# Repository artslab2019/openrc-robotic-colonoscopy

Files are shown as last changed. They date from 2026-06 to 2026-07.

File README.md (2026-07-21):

# OpenRC: An Open-Source Robotic Colonoscopy Framework for Multimodal Data Acquisition and Autonomy Research

**MICCAI 2026** &nbsp;·&nbsp; Siddhartha Kapuria, Mohammad Rafiee Javazm, Naruhiko Ikoma, Joga Ivatury, Mohammad Ali Nasseri, Nassir Navab, Farshid Alambeigi





OpenRC is an open-source framework that **robotizes a conventional clinical colonoscope without altering its workflow.** A modular robotic platform actuates the scope's existing insertion-tube and steering knobs while simultaneously recording the endoscopic video, operator commands, low-level actuation signals, and the distal-tip pose. The result is a reproducible testbed for studying robotic colonoscopy, imitation/vision-language-action learning, and surgical autonomy. 

This repository provides a higher-level-of-detail overview of the **hardware platform** and the **colon phantom testbed**. Full analytical design, optimization, and fabrication derivations are documented in our companion paper, [arXiv:2509.10735](https://arxiv.org/abs/2509.10735).

This repository also includes the OpenRC dataset release accompanying this platform. The dataset consists of synchronized multimodal trajectories collected using this platform on real colon phantoms, spanning navigation, scanning, and failure/recovery scenarios.

---

## System Overview

OpenRC system overview

OpenRC is organized into four interconnected subsystems:

1. **Control System** — operator interface and onboard compute.
2. **Robotic System** — the clip-on actuation hardware (feeding + bending modules).
3. **Video Capture** — clinical imaging chain and frame acquisition.
4. **Environment & Sensing** — the colon phantom and electromagnetic tip tracking.

---

## Experimental Setup

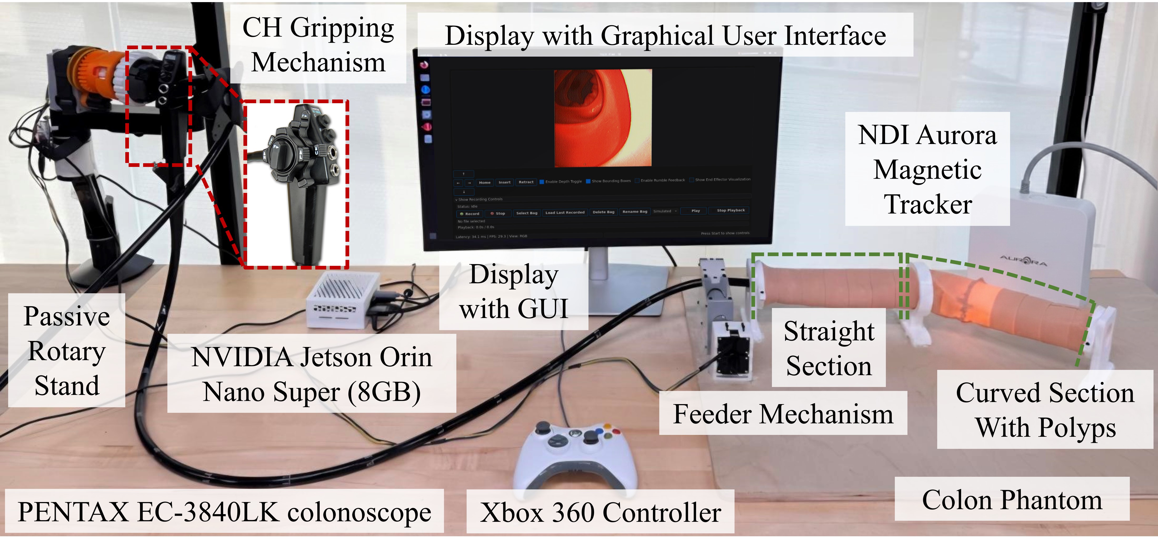
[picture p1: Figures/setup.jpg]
OpenRC experimental setup


The complete benchtop testbed. A **PENTAX EC-3840LK colonoscope** is held on a passive rotary stand, with its distal end gripped by the **CH (collet-chuck) bending mechanism** and its insertion tube driven by the **feeder mechanism**. An **Xbox 360 controller** teleoperates the scope through the **NVIDIA Jetson Orin Nano Super (8 GB)**, which also runs the **GUI** shown on the display. The scope is navigated through a custom **colon phantom** while the **NDI Aurora magnetic tracker** records 6-DoF distal-tip pose.

---

## Hardware Platform

OpenRC is a **retrofit**: it clamps onto an unmodified clinical colonoscope and drives the same insertion tube and steering knobs a clinician would operate by hand. Two decoupled, 3D-printable modules provide the actuation, while teleoperation, compute, and synchronized recording run onboard an NVIDIA Jetson.

| | |
|---|---|
| **Compute** | NVIDIA Jetson Orin Nano Super (8 GB) |
| **Control** | Xbox controller → ROS2 Humble → Dynamixel U2D2 |
| **Feeding module** | 1-DoF insertion/retraction via a motor-driven spline shaft and feeder-roller |
| **Bending module** | Steering via a nested collet-chuck gripping the scope's existing knobs |
| **Imaging** | Clinical video processor + frame grabber, 383 × 396 @ 30 fps |
| **Sensing** | NDI Aurora EM tracker, 6-DoF distal-tip pose |
| **Scope** | PENTAX EC-3840LK (unmodified) |

The two fabricated actuation modules:

Assembled feeding module

*Feeding module — a motor drives the spline shaft through a flexible coupling, advancing the scope's insertion tube.*

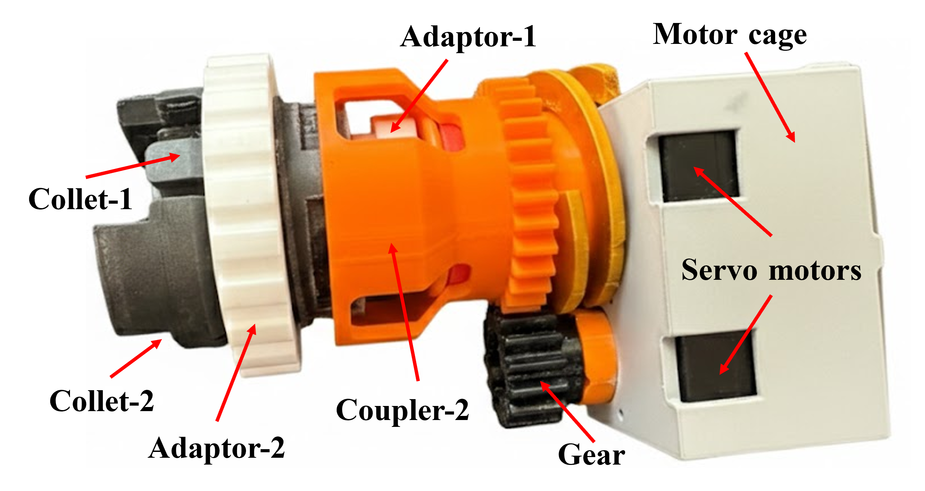
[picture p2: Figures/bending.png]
Assembled bending module


*Bending module — nested collets clamp onto the concentric steering knobs and are driven through a gear train to deflect the distal tip.*

> **Further details are provided in [`docs/`](docs/):** mechanical design and CAD ([Hardware Platform](docs/hardware.md)), the ROS2 control architecture ([Software & ROS2 Stack](docs/software.md)), and the phantom build ([Colon Phantom Fabrication](docs/phantom-fabrication.md)). For the analytical design and optimization, see the companion paper [arXiv:2509.10735](https://arxiv.org/abs/2509.10735).

---

## Documentation

| Document | Contents |
|---|---|
| [Hardware Platform](docs/hardware.md) | Control system, feeding/bending modules (CAD + dimensions), video capture, sensing |
| [Software & ROS2 Stack](docs/software.md) | ROS2 node graph, topics, and control/recording architecture (implementation details) |
| [Colon Phantom Fabrication](docs/phantom-fabrication.md) | Polyp and colon-wall molding/casting procedure |
| [Bill of Materials](docs/bill-of-materials.md) | Components, part numbers, and suppliers |
| [CAD & Assembly Files](docs/assembly.md) | STEP assembly exports and STL files for printable parts |

---

## Dataset

The OpenRC dataset is hosted on HuggingFace in **[LeRobot](https://github.com/huggingface/lerobot) format**, under NVIDIA's PhysicalAI Open-H-Embodiment collection:

> **`nvidia/PhysicalAI-Robotics-Open-H-Embodiment`** → [`Endoscopy/ut_austin/arts_lab/colonoscope_lerobot`](https://huggingface.co/datasets/nvidia/PhysicalAI-Robotics-Open-H-Embodiment/tree/main/Endoscopy/ut_austin/arts_lab/colonoscope_lerobot)

| | |
|---|---|
| **Episodes** | 1,894 teleoperated trajectories |
| **Frames** | 2,095,587 (~19.4 hours) |
| **Camera** | 383 × 396 endoscopic video @ 30 fps |
| **Size** | 19.7 GB |
| **Recording** | ROS2 Humble; calibration-based time alignment across streams |
| **Collection** | 5 intermediate-skill operators, 10 structured task variations, Nov 2025 – Jan 2026 |
| **License** | CC BY 4.0 |

**Task variations** span routine navigation, induced failure events, and recovery behaviors.

### Example Episode

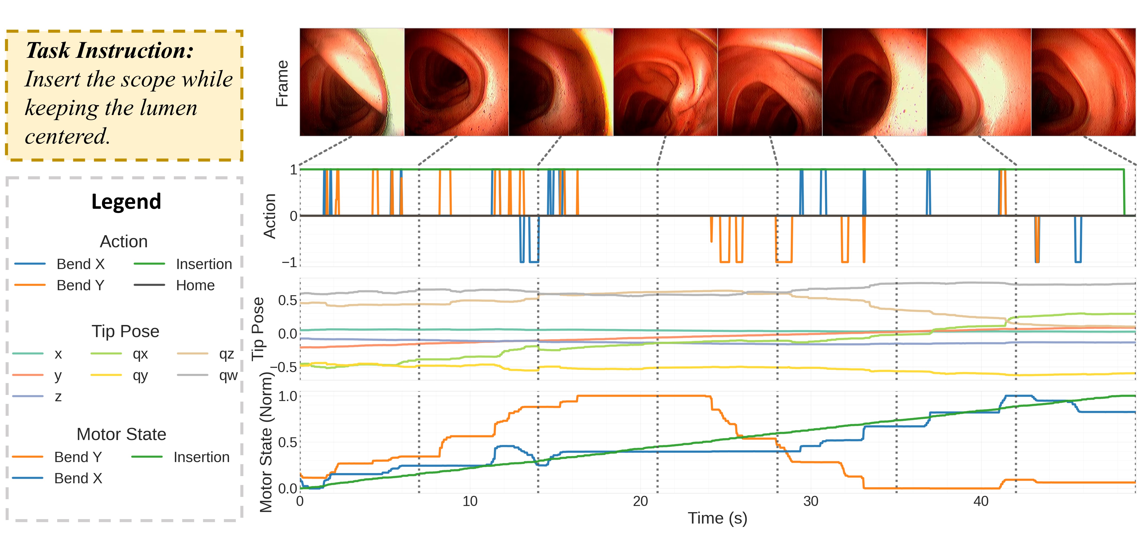
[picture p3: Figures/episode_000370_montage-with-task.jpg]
Example OpenRC episode


A representative episode (`episode_000370`) for the task *"Insert the scope while keeping the lumen centered."* The top row shows sampled endoscopic frames; below, the synchronized operator **action** (bend X/Y, insertion, home), 7-DoF **tip pose** from the EM tracker, and low-level **motor state** are plotted over the episode timeline — illustrating how all streams are time-aligned within each trajectory.

### Modalities & Schema

- **Endoscopic video** — RGB camera feed (384 × 383 @ 30 fps).
- **NDI Aurora EM tracking** — distal-tip pose.
- **Xbox controller** — operator teleoperation inputs.

| Key | dtype / shape | Description |
|-----|---|---|
| `observation.images.endoscope` | video `[396, 383, 3]` | Endoscopic RGB camera feed (AV1 / yuv420p) |
| `observation.state` | int32 `[3]` | Motor positions: `motor_1`, `motor_2`, `motor_3` |
| `observation.ndi_cartesian_absolute` | float32 `[7]` | Absolute tip pose in NDI frame: `x, y, z, qx, qy, qz, qw` |
| `observation.ndi_cartesian_relative` | float32 `[6]` | Relative tip motion: `dx, dy, dz, droll, dpitch, dyaw` |
| `action` | float32 `[4]` | `bend_x`, `bend_y`, `insertion`, `home` (ranges: `[-1, 1]` for bend/insertion, `[0, 1]` for home) |

### Quickstart

The dataset uses **LeRobot format v2.1**, which requires **`lerobot==0.33`**.

1. Install `torch` by following the [official PyTorch installation instructions](https://pytorch.org/get-started/locally/).
2. Install the remaining dataset and visualization dependencies:

```bash
pip install huggingface_hub "lerobot==0.33" numpy tqdm rerun
```

3. Download the dataset subset from HuggingFace:

```python
from huggingface_hub import snapshot_download

local_dir = snapshot_download(
    repo_id="nvidia/PhysicalAI-Robotics-Open-H-Embodiment",
    repo_type="dataset",
    allow_patterns="Endoscopy/ut_austin/arts_lab/colonoscope_lerobot/*",
)
print("Downloaded to:", local_dir)
```

4. Load it with the LeRobot API from the downloaded subfolder:

```python
from lerobot.common.datasets.lerobot_dataset import LeRobotDataset

dataset = LeRobotDataset(
    repo_id="nvidia/PhysicalAI-Robotics-Open-H-Embodiment",
    root=f"{local_dir}/Endoscopy/ut_austin/arts_lab/colonoscope_lerobot",
)

print(dataset)
sample = dataset[0]            # a single frame with video + state + action
print(sample.keys())
```

### Visualization

The repository includes [`lerobot_dataset_viz.py`](lerobot_dataset_viz.py), a small Rerun-based viewer for inspecting dataset episodes frame-by-frame.

Example:

```bash
python lerobot_dataset_viz.py \
    --repo-id nvidia/PhysicalAI-Robotics-Open-H-Embodiment \
    --episode-index 370 \
    --root /path/to/snapshot_download/Endoscopy/ut_austin/arts_lab/colonoscope_lerobot
```

By default the script opens a local Rerun viewer. Pass `--save 1 --output-dir path/to/dir` to write an `.rrd` file instead, or use `--mode distant` to stream from a remote machine.

See the [dataset card](https://huggingface.co/datasets/nvidia/PhysicalAI-Robotics-Open-H-Embodiment/blob/main/Endoscopy/ut_austin/arts_lab/colonoscope_lerobot/README.md) for the authoritative feature schema and any version-specific loading notes.

---

## Release Roadmap

- [x] Dataset release (HuggingFace, LeRobot format).
- [x] Hardware, software, and phantom-fabrication documentation ([`docs/`](docs/)).
- [x] CAD release for feeding and bending modules: STEP assembly exports and STL files for printable parts.
- [ ] Complete the [Bill of Materials](docs/bill-of-materials.md) with remaining phantom-material details.

---

## Citation

If you use OpenRC or its dataset, please cite:

```bibtex
@inproceedings{kapuria2026openrc,
  title     = {OpenRC: An Open-Source Robotic Colonoscopy Framework for Multimodal Data Acquisition and Autonomy Research},
  author    = {Kapuria, Siddhartha and Rafiee Javazm, Mohammad and Ikoma, Naruhiko and Ivatury, Joga and Nasseri, Mohammad Ali and Navab, Nassir and Alambeigi, Farshid},
  booktitle = {Medical Image Computing and Computer Assisted Intervention (MICCAI)},
  year      = {2026},
  eprint    = {2604.03781},
  archivePrefix = {arXiv},
  % TODO: update pages/publisher/DOI when the proceedings are published
}
```

The mechanical design and modeling of the feeding and bending modules:

```bibtex
@article{rafieejavazm2025endoscopy,
  title   = {Analytical Design and Development of a Modular and Intuitive Framework for Robotizing and Enhancing the Existing Endoscopic Procedures},
  author  = {Rafiee Javazm, Mohammad and Kulkarni, Yash and Xue, Jiaqi and Ikoma, Naruhiko and Alambeigi, Farshid},
  journal = {arXiv preprint arXiv:2509.10735},
  year    = {2025},
}
```

---

## License & Acknowledgements

The dataset is released under **[CC BY 4.0](https://creativecommons.org/licenses/by/4.0/)** and hosted within NVIDIA's PhysicalAI Open-H-Embodiment collection. Hardware and phantom development were carried out at the Advanced Robotic Technologies for Surgery (ARTS) Lab, The University of Texas at Austin, and Rice University and the Bookout Center at Houston Methodist Hospital. This work was supported by the National Cancer Institute of the National Institutes of Health under Award Number R21CA280747.

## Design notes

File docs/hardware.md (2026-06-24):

# Hardware Platform

[← Back to README](../README.md)

> For the full analytical design, parameter-optimization spaces, and mechanical fabrication of the feeding and bending modules, see the companion paper [arXiv:2509.10735](https://arxiv.org/abs/2509.10735). The summary below is intended as a platform-level overview. For part numbers and quantities see the [Bill of Materials](bill-of-materials.md); for STEP assembly exports and printable STL files see [CAD & Assembly Files](assembly.md).

OpenRC is organized into four interconnected subsystems:

1. **Control System** — operator interface and onboard compute.
2. **Robotic System** — the clip-on actuation hardware (feeding + bending modules).
3. **Video Capture** — clinical imaging chain and frame acquisition.
4. **Environment & Sensing** — the colon phantom and electromagnetic tip tracking.

---

## Control System

Teleoperation is handled by a standard **Xbox controller**, with real-time control and data logging running onboard an **NVIDIA Jetson Orin Nano Super**. A graphical user interface displays the live endoscopic feed and system state. Motor commands are dispatched from the Jetson through a **DYNAMIXEL U2D2** (USB ↔ RS-485 bridge) to the three servos, which are wired as an **RS-485 daisy chain** (ROBOTIS, South Korea).

| Input | Action |
|---|---|
| `R2` (right trigger) | Retraction |
| `L2` (left trigger) | Insertion |
| Analog stick | Bending (steering, X/Y) |
| `L3` (stick press) | Reset / home |

The ROS2 software stack that ties these nodes together is documented separately in [Software & ROS2 Stack](software.md).

---

## Robotic System

The robotic system is a retrofit: it clamps onto an unmodified colonoscope and drives the same insertion tube and control knobs a clinician would operate by hand. It comprises two decoupled modules.

### Feeding Module

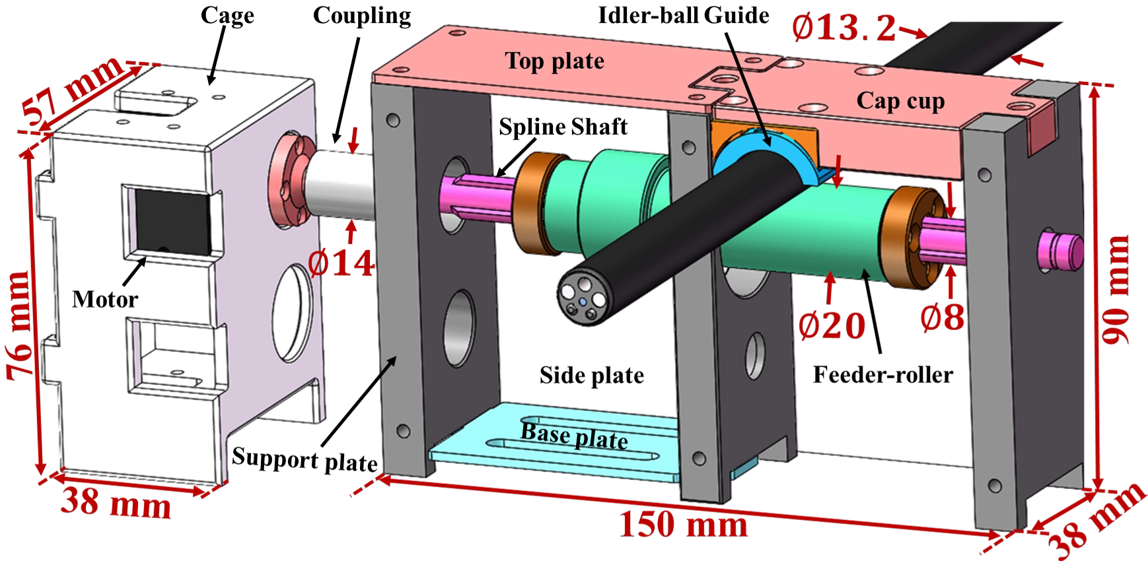
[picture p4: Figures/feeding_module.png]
Feeding module design


The feeding module provides the single insertion/retraction degree of freedom. A single **DYNAMIXEL XM430-W350-R** servo (1:350 gearbox, 12-bit absolute encoder, 0.088° resolution) drives a **spline shaft** coupled to a **feeder-roller** that grips the insertion tube, while an opposing **idler-ball guide** maintains contact pressure and keeps the tube aligned as it is advanced or withdrawn. The module is packaged in a compact rigid cage (≈ 150 × 90 × 38 mm) that mounts at the scope entry point.

Assembled feeding module

*The fabricated feeding module: a motor drives the spline shaft through a flexible coupling, advancing the colonoscope's insertion tube. The X/Y/Z axes denote the local tip frame.*

### Bending Module

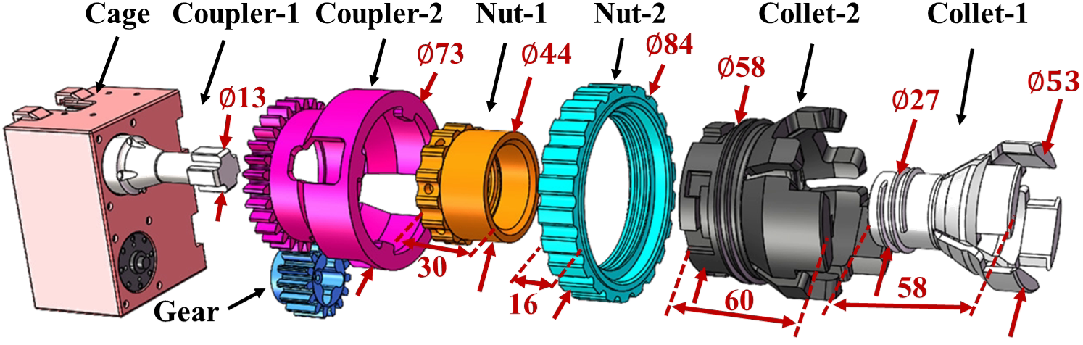
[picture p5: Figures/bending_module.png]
Bending module design


The bending module actuates the scope's steering (knob) degrees of freedom using a **nested collet-chuck** design. Concentric collets and couplers grip the existing up/down and left/right steering knobs without modification, and two gear-driven **DYNAMIXEL XM540-W270-R** servos (1:270 gearbox, 12-bit absolute encoder, 0.088° output resolution) — commanded through the U2D2 — rotate them to deflect the distal tip. This preserves the native tendon-driven steering mechanism of the scope while making it programmatically controllable.

Assembled bending module

*The fabricated bending module: nested collets (Collet-1/2) and adaptors/couplers clamp onto the concentric steering knobs, while servo motors drive them through a gear train to deflect the distal tip.*

---

## Video Capture

Imaging uses the clinical chain end-to-end: the scope's optics are illuminated and processed by a PENTAX **EPM-3300** video processor & light source, whose output is digitized by a **ClearClick Video-to-USB 1080P capture device** (ClearClick, USA) and streamed to the compute unit. The endoscopic video is captured at **383 × 396 resolution, 30 fps**.

---

## Environment & Sensing

Distal-tip localization is provided by an **NDI Aurora electromagnetic (EM) tracker**, yielding 6-DoF tip pose (position + orientation) co-registered with the video and actuation streams. The robotized scope is exercised against a custom **colon phantom** with embedded polyps — see [Colon Phantom Fabrication](phantom-fabrication.md).

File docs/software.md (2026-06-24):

# Software & ROS2 Stack

[← Back to README](../README.md)

OpenRC ROS2 node graph

The control software is implemented as a **ROS2 Humble** stack running on the Jetson Orin Nano Super. Each hardware interface and processing step is a separate node, communicating over standard topics. This node-based decomposition is what enables synchronized, multi-stream recording: every stream is timestamped and aligned (calibration-based time alignment across topics) to produce the dataset trajectories.

## Nodes & Topics

| Node | Role | Publishes / Subscribes |
|---|---|---|
| **Joy Input Node** | Reads the Xbox controller | publishes `/joy` |
| **Control Node** | Maps operator commands to motor targets; dispatches them through the U2D2 to the actuator microcontroller | subscribes `/joy`; reads back `encoder_states` |
| **Camera Node** | Grabs frame-grabber output | publishes `image_raw` |
| **NDI Aurora Node** | Streams distal-tip pose from the EM tracker | publishes tip `position` |
| **GUI Node** | Renders the live operator display | subscribes to video, motor state, and tip-pose topics |

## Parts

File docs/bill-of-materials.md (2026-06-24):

# Bill of Materials

[← Back to README](../README.md)

Components used in the OpenRC platform.

The tables below list the off-the-shelf hardware, reference hardware, and printable STL parts. Refer to [`Feeder-Assembly-V3.STEP`](../CAD/Feeding/STEP/Feeder-Assembly-V3.STEP) and [`Bending-Assembly.STEP`](../CAD/Bending/STEP/Bending-Assembly.STEP) to see how the parts come together.

## Actuation & Control

| Component | Part / Model | Qty | Supplier | Approx. cost | Notes |
|---|---|-----|---|---|---|
| Servo motor (bending) | DYNAMIXEL XM540-W270-R | 2 | ROBOTIS (South Korea) | ~$495 ea | 1:270 gearbox, 12-bit absolute encoder, 0.088° output resolution; drives the steering knobs |
| Servo motor (feeding) | DYNAMIXEL XM430-W350-R | 1 | ROBOTIS (South Korea) | ~$335 | 1:350 gearbox, 12-bit absolute encoder, 0.088° resolution; drives the spline shaft |
| Serial controller | DYNAMIXEL U2D2 | 1 | ROBOTIS (South Korea) | ~$35 | USB ↔ RS-485 bridge |
| Motor bus | RS-485 daisy chain | 1 | ROBOTIS (South Korea) | ~$10 | Connects the three servos to the U2D2 |
| Onboard compute | NVIDIA Jetson Orin Nano Super (8 GB) | 1 | NVIDIA | ~$249 | Runs the ROS2 stack |
| Teleop input | Xbox 360 controller | 1 | Microsoft | ~$30 | |

## Imaging

| Component | Part / Model | Qty | Supplier | Approx. cost | Notes |
|---|---|-----|---|---|---|
| Colonoscope | PENTAX EC-3840LK | 1 | PENTAX Medical | quote (clinical) | Unmodified clinical scope; refurbished-market price varies |
| Video processor & light source | EPM-3300 | 1 | PENTAX Medical | quote (clinical) | Refurbished-market price varies |
| Frame grabber | Video to USB 1080P Capture device | 1 | ClearClick (USA) | ~$70 | Digitizes the video output |

## Sensing

| Component | Part / Model | Qty | Supplier | Approx. cost | Notes |
|---|---|-----|---|---|---|
| EM tracker | NDI Aurora | 1 | Northern Digital Inc. | quote (OEM) | 6-DoF distal-tip pose; sold as an OEM solution, price on request |

## Mechanical / Structure

### Purchased / Reference Mechanical Components

| Component | Part / Model | Qty | Supplier | Buy link | Notes |
|---|---|-----|---|---|---|
| Feeding lead screw | 97783A170 | 1 | McMaster-Carr | [97783A170](https://www.mcmaster.com/97783A170/) | 100 mm lead screw; CAD reference in [`100mm-Lead Screw_97783A170.STEP`](../CAD/Feeding/STEP/100mm-Lead%20Screw_97783A170.STEP) |
| Feeding ball bearing | 7804K117 | 1 | McMaster-Carr | [7804K117](https://www.mcmaster.com/7804K117/) | Stainless steel ball bearing; CAD reference in [`7804K117_Stainless Steel Ball Bearing_7804K117.STEP`](../CAD/Feeding/STEP/7804K117_Stainless%20Steel%20Ball%20Bearing_7804K117.STEP) |
| Bending compression spring | 2006N518 | 1 | McMaster-Carr | [2006N518](https://www.mcmaster.com/2006N518/) | 302 stainless steel corrosion-resistant compression spring; CAD reference in [`2006N518_302 Stainless Steel Corrosion-Resistant Compression Springs_2006N518.STEP`](../CAD/Bending/STEP/2006N518_302%20Stainless%20Steel%20Corrosion-Resistant%20Compression%20Springs_2006N518.STEP) |
| Bending plastic sliding bearing | GSM-4448-16 | 2 | igus | [GSM-4448-16 search](https://www.igus.com/search?q=GSM-4448-16) | Plastic sliding bearing; CAD reference in [`GSM_4448_16_2.STEP`](../CAD/Bending/STEP/GSM_4448_16_2.STEP) |

### Feeding Module STL Exports

| Component | STL file |
|---|---|
| Actuation module assembly | [`feeding-actuation-module.stl`](../CAD/Feeding/STL/feeding-actuation-module.stl) |
| Base plate | [`feeding-base-plate.stl`](../CAD/Feeding/STL/feeding-base-plate.stl) |
| Top plate | [`feeding-top-plate.stl`](../CAD/Feeding/STL/feeding-top-plate.stl) |
| Side plate | [`feeding-side-plate.stl`](../CAD/Feeding/STL/feeding-side-plate.stl) |
| End support, left | [`feeding-end-support-left.stl`](../CAD/Feeding/STL/feeding-end-support-left.stl) |
| End support, mid | [`feeding-end-support-mid.stl`](../CAD/Feeding/STL/feeding-end-support-mid.stl) |
| End support, right | [`feeding-end-support-right.stl`](../CAD/Feeding/STL/feeding-end-support-right.stl) |
| Half bearing, 1 | [`feeding-half-bearing-1.stl`](../CAD/Feeding/STL/feeding-half-bearing-1.stl) |
| Half bearing, 2 | [`feeding-half-bearing-2.stl`](../CAD/Feeding/STL/feeding-half-bearing-2.stl) |
| Motor coupler | [`feeding-motor-coupler.stl`](../CAD/Feeding/STL/feeding-motor-coupler.stl) |
| Coupler | [`feeding-coupler.stl`](../CAD/Feeding/STL/feeding-coupler.stl) |
| Nut connector | [`feeding-nut-connector.stl`](../CAD/Feeding/STL/feeding-nut-connector.stl) |
| Spline nut, 1 | [`feeding-spline-nut-1.stl`](../CAD/Feeding/STL/feeding-spline-nut-1.stl) |
| Spline nut, 2 | [`feeding-spline-nut-2.stl`](../CAD/Feeding/STL/feeding-spline-nut-2.stl) |
| Spline shaft | [`feeding-spline-shaft.stl`](../CAD/Feeding/STL/feeding-spline-shaft.stl) |
| Cap | [`feeding-cap.stl`](../CAD/Feeding/STL/feeding-cap.stl) |

### Bending Module STL Exports

| Component | STL file |
|---|---|
| Motor cage, S | [`bending-motor-cage-s.stl`](../CAD/Bending/STL/bending-motor-cage-s.stl) |
| Motor cage, variant | [`bending-motor-cage-2.stl`](../CAD/Bending/STL/bending-motor-cage-2.stl) |
| Motor coupling | [`bending-motor-coupler.stl`](../CAD/Bending/STL/bending-motor-coupler.stl) |
| Collet, 1 | [`bending-collet-1.stl`](../CAD/Bending/STL/bending-collet-1.stl) |
| Collet, 2 | [`bending-collet-2.stl`](../CAD/Bending/STL/bending-collet-2.stl) |
| Adaptor, 1 | [`bending-adaptor-1.stl`](../CAD/Bending/STL/bending-adaptor-1.stl) |
| Adaptor, 2 | [`bending-adaptor-2.stl`](../CAD/Bending/STL/bending-adaptor-2.stl) |
| Coupling, 1 | [`bending-coupling-1.stl`](../CAD/Bending/STL/bending-coupling-1.stl) |
| Coupling, 2 | [`bending-coupling-2.stl`](../CAD/Bending/STL/bending-coupling-2.stl) |
| Coupling, 3 | [`bending-coupling-3.stl`](../CAD/Bending/STL/bending-coupling-3.stl) |

## Phantom Materials

| Material | Part / Model | Supplier | Approx. cost | Notes |
|---|---|---|---|---|
| Colon wall silicone | Ecoflex 00-30 | Smooth-On | ~$33 (2 lb) | Body of the phantom |
| Seam sealant | Ecoflex 00-35 Fast | Smooth-On | ~$40 (trial) | Joins segments |
| Polyp silicone | `TODO` (Smooth-On) | Smooth-On | `TODO` | Flesh-tone pigmented |
| Mold release | Ease Release 200 | Mann Technologies | ~$19 (12 oz) | |
| Pigment | `TODO` | Smooth-On | `TODO` | Flesh-tone |

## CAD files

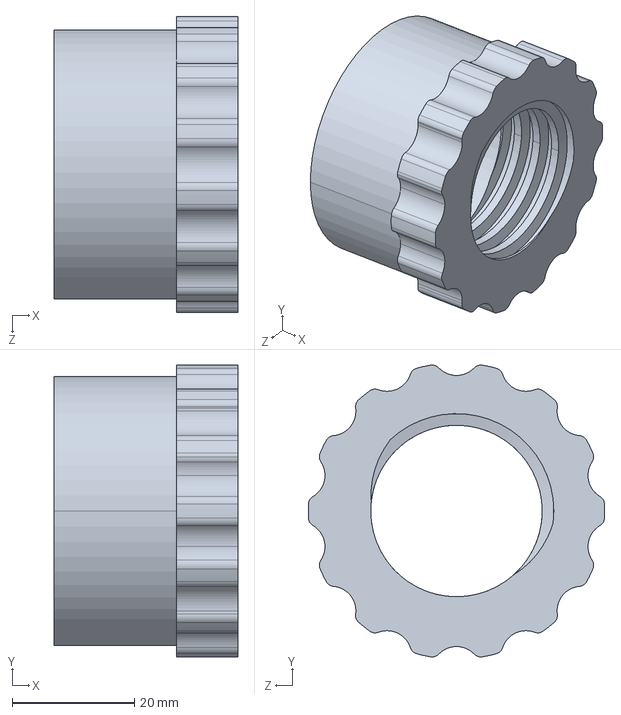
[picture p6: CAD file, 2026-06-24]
CAD/Bending/STEP/Adptor-1_默认.STEP
30.0 x 47.7 x 48.4 mm

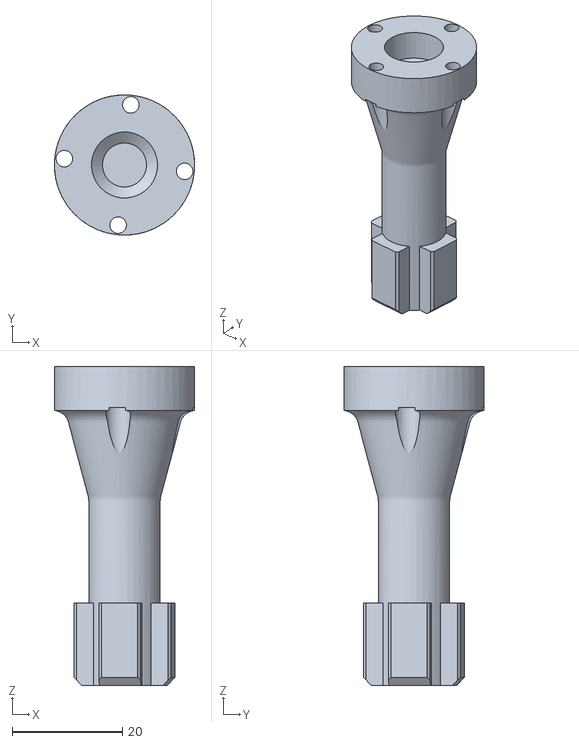
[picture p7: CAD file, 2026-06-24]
CAD/Bending/STL/bending-coupling-1.stl
25.5 x 25.5 x 58.0

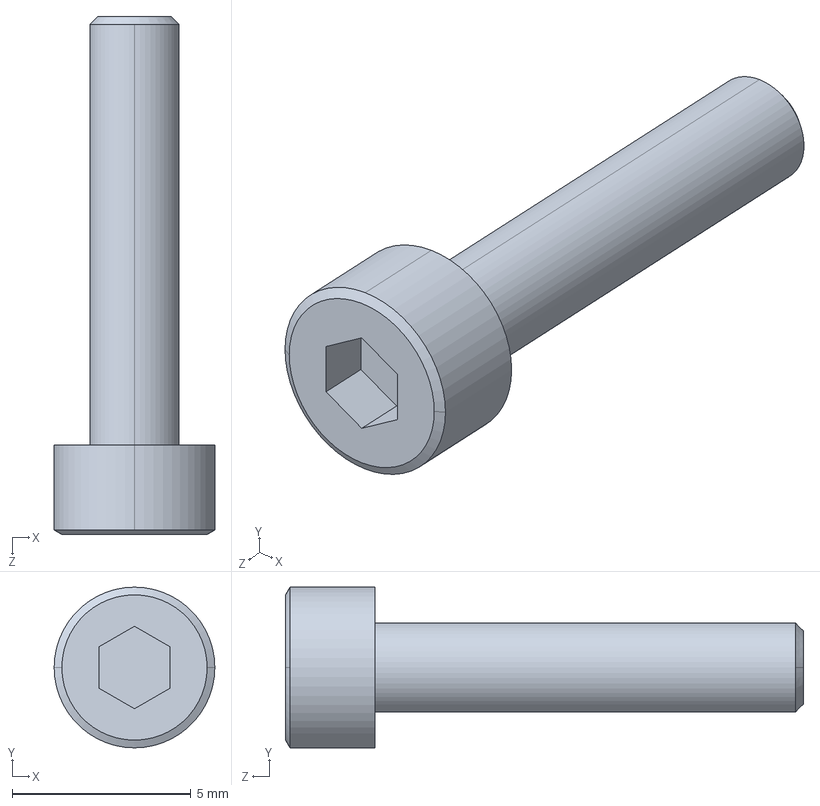
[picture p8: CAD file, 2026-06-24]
CAD/Feeding/STEP/WBH_M2_5X12.stp.STEP
4.50 x 4.50 x 14.5 mm

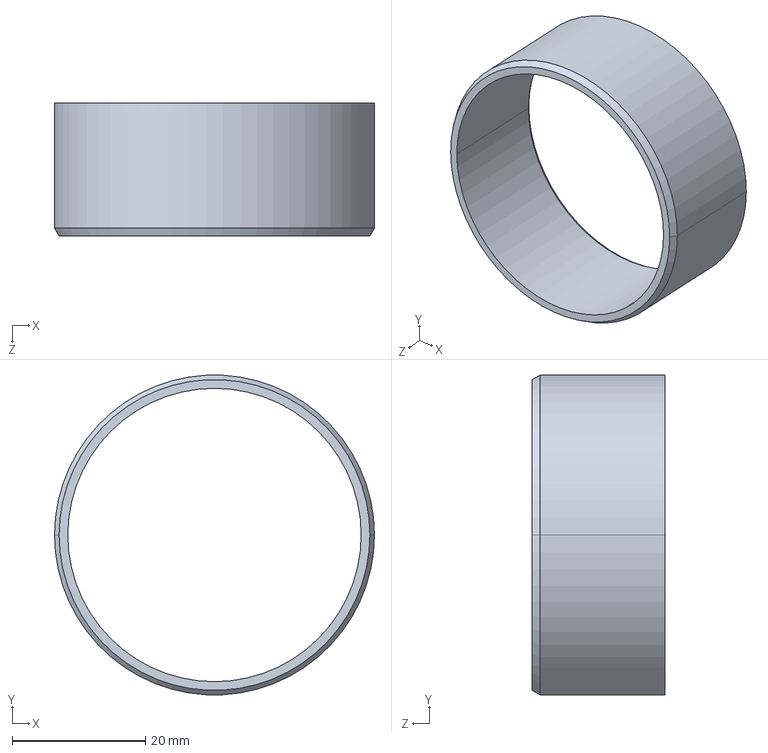
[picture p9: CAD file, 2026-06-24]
CAD/Bending/STEP/2023_01_25_20_50_19_0381.stp.STEP
48.0 x 47.9 x 20.0 mm

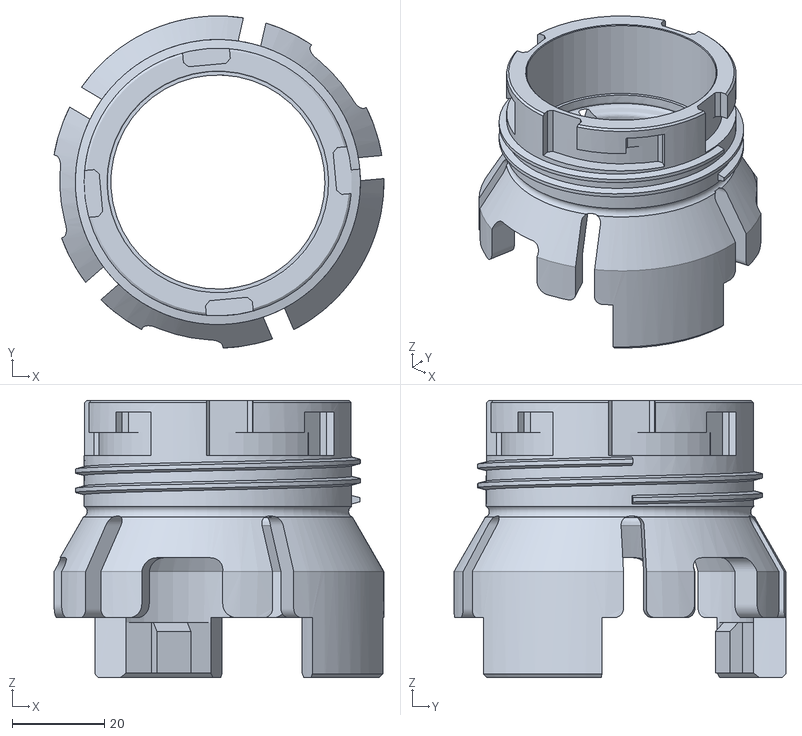
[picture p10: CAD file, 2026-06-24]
CAD/Bending/STL/bending-collet-2.stl
71.5 x 72.0 x 60.1

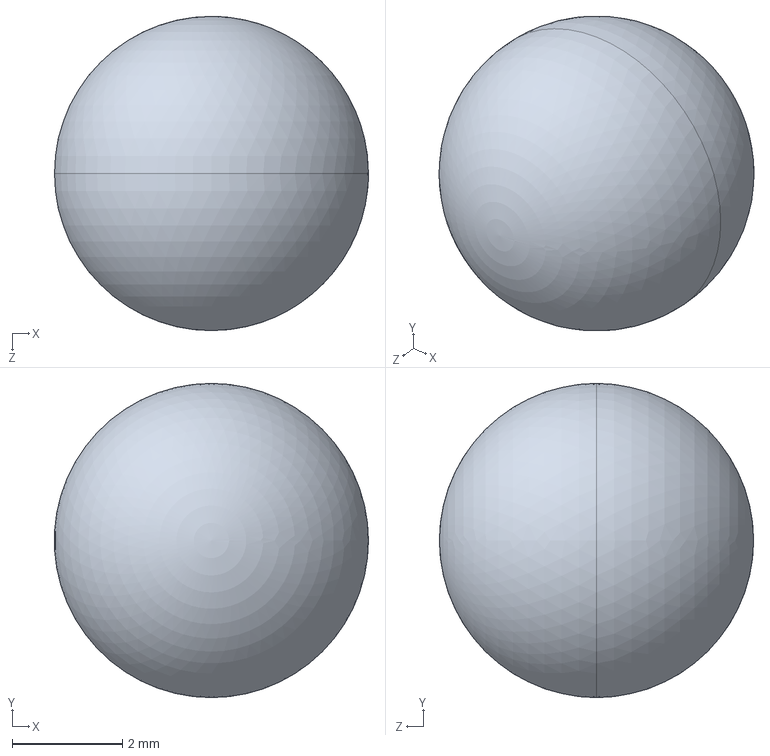
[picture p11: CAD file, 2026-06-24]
CAD/Feeding/STEP/Ball.STEP
5.70 x 5.70 x 5.70 mm

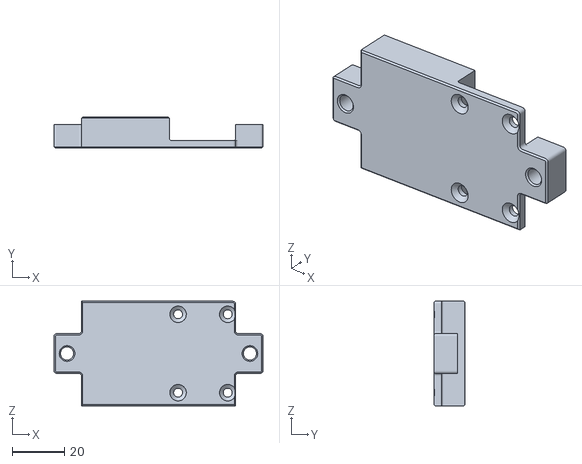
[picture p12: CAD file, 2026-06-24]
CAD/Feeding/STL/feeding-cap.stl
80.0 x 12.0 x 40.0

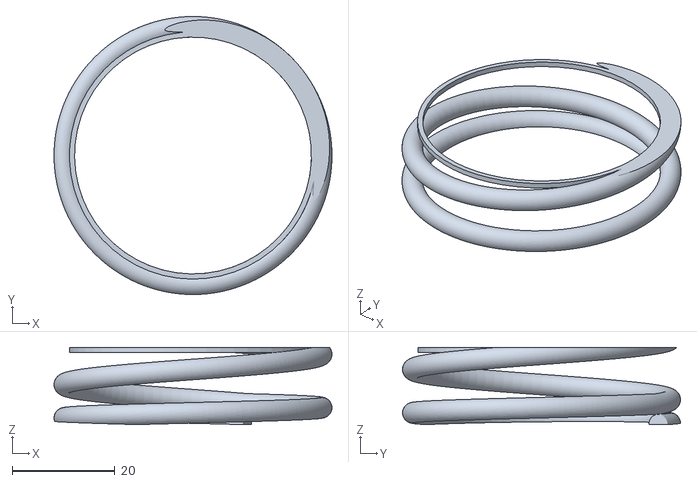
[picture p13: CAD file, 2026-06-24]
CAD/Bending/STL/bending-compression-spring-2006n518.stl
54.0 x 54.0 x 15.0

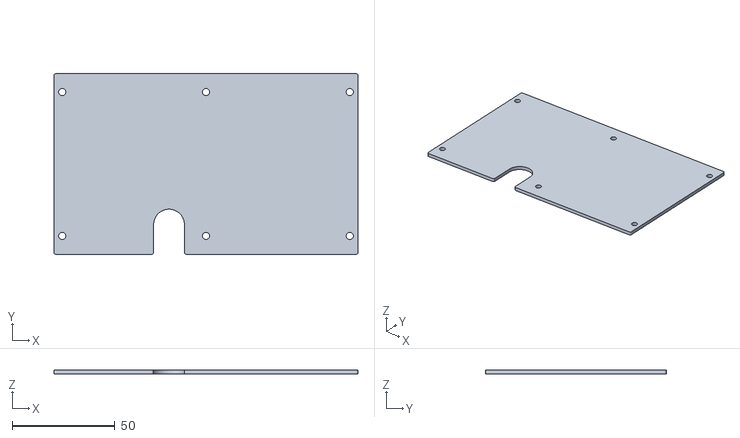
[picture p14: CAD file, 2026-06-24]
CAD/Feeding/STL/feeding-side-plate.stl
148.0 x 88.0 x 2.00

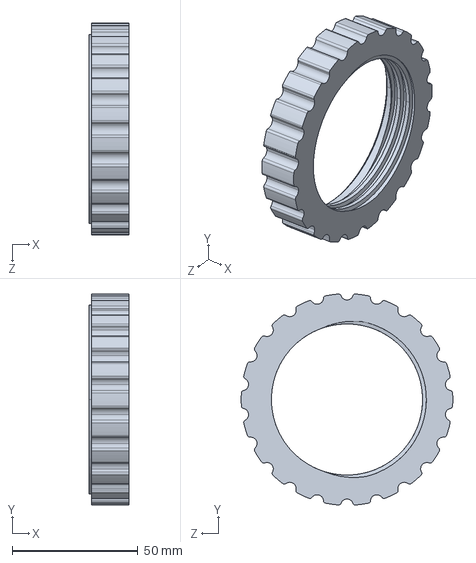
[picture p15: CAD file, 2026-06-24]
CAD/Bending/STEP/Adptor-2-V2_默认.STEP
16.0 x 83.7 x 84.0 mm

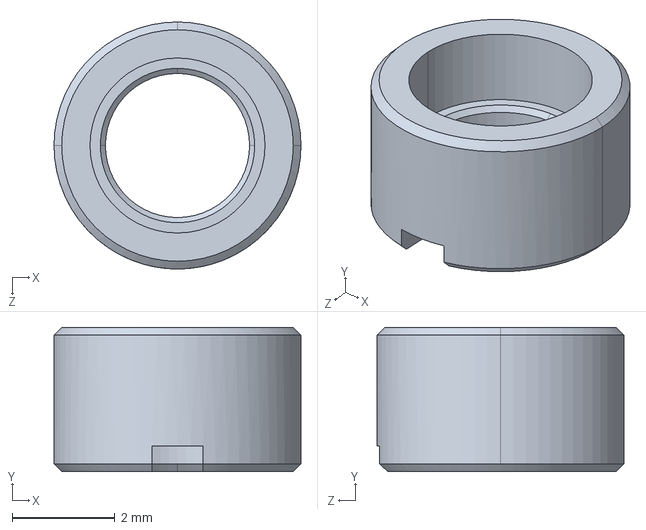
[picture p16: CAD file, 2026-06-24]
CAD/Feeding/STEP/DC12_A01_SPACER_RING_1.stp.STEP
4.80 x 2.80 x 4.80 mm

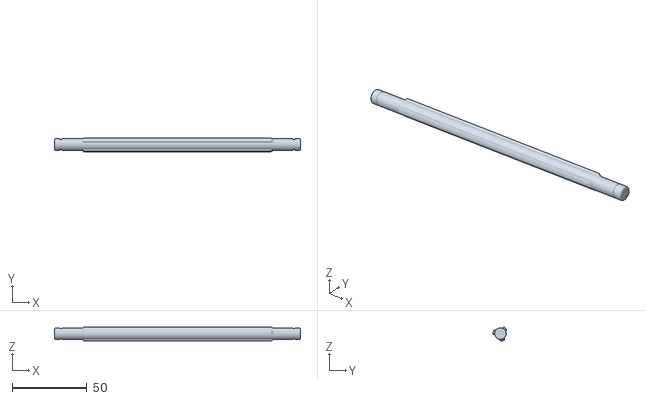
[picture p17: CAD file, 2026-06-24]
CAD/Feeding/STL/feeding-spline-shaft.stl
165.0 x 9.32 x 9.53

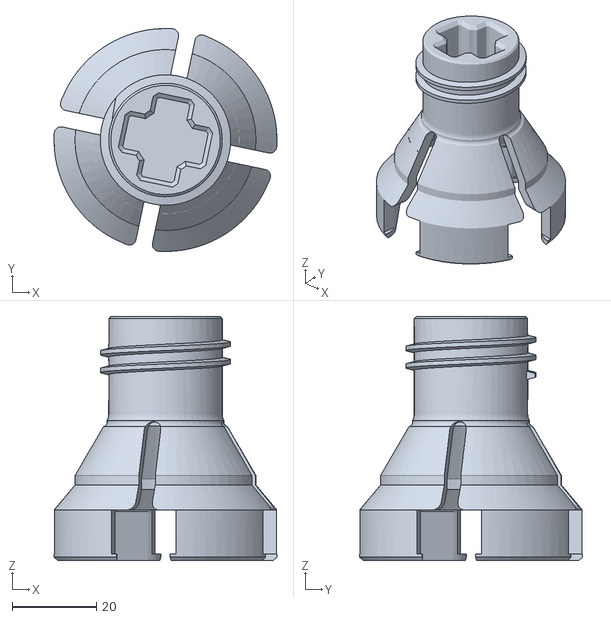
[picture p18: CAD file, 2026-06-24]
CAD/Bending/STL/bending-collet-1.stl
53.0 x 53.0 x 58.0

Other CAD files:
CAD/Bending/STEP/Bending-Assembly.STEP
CAD/Feeding/STEP/Feeder-Assembly-V3.STEP
CAD/Bending/STEP/GSM_4448_20_2.stp.STEP
CAD/Feeding/STEP/装配体1_默认.STEP
CAD/Bending/STL/bending-sliding-bearing-gsm-4448-16.stl
CAD/Bending/STEP/2006N518_302 Stainless Steel Corrosion-Resistant Compression Springs_2006N518.STEP
CAD/Bending/STEP/Collet-1-NewV.STEP
CAD/Bending/STEP/Collet-2-NewV.STEP
CAD/Bending/STEP/Couping-1-NewV.STEP
CAD/Bending/STEP/Couping-2-V3.STEP
CAD/Bending/STEP/Couping-3_默认.STEP
CAD/Bending/STEP/GSM_4448_16_2.STEP
CAD/Bending/STEP/MotorCage-2_默认.STEP
CAD/Bending/STEP/MotorCage-S_默认.STEP
CAD/Bending/STEP/MotorCouple.STEP
CAD/Bending/STEP/XM,H,D-540.N101.I101.STEP
CAD/Bending/STL/bending-adaptor-1.stl
CAD/Bending/STL/bending-adaptor-2.stl
CAD/Bending/STL/bending-coupling-2.stl
CAD/Bending/STL/bending-coupling-3.stl
CAD/Bending/STL/bending-motor-cage-2.stl
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

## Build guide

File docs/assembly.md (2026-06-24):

# CAD & Assembly Files

[← Back to README](../README.md)

The released CAD package provides STEP assembly exports and STL files for the printable parts. Use it together with the [Bill of Materials](bill-of-materials.md) for the off-the-shelf components and the [Hardware Platform](hardware.md) for the design rationale.

## Files

- **STEP (`.STEP`) assembly exports** for the feeding and bending modules.
- **STL (`.stl`) files** for the printable feeding and bending module parts.

## Assembly References

- Feeding module: [`Feeder-Assembly-V3.STEP`](../CAD/Feeding/STEP/Feeder-Assembly-V3.STEP)
- Bending module: [`Bending-Assembly.STEP`](../CAD/Bending/STEP/Bending-Assembly.STEP)

## Reproducing the build

1. Open the STEP assembly export to inspect how the parts fit together.
2. Print the STL parts; we printed the parts in PLA.
3. Source the off-the-shelf components from the [Bill of Materials](bill-of-materials.md).
4. Fabricate the colon phantom following [Colon Phantom Fabrication](phantom-fabrication.md).

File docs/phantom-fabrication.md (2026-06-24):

# Colon Phantom Testbed & Fabrication

[← Back to README](../README.md)

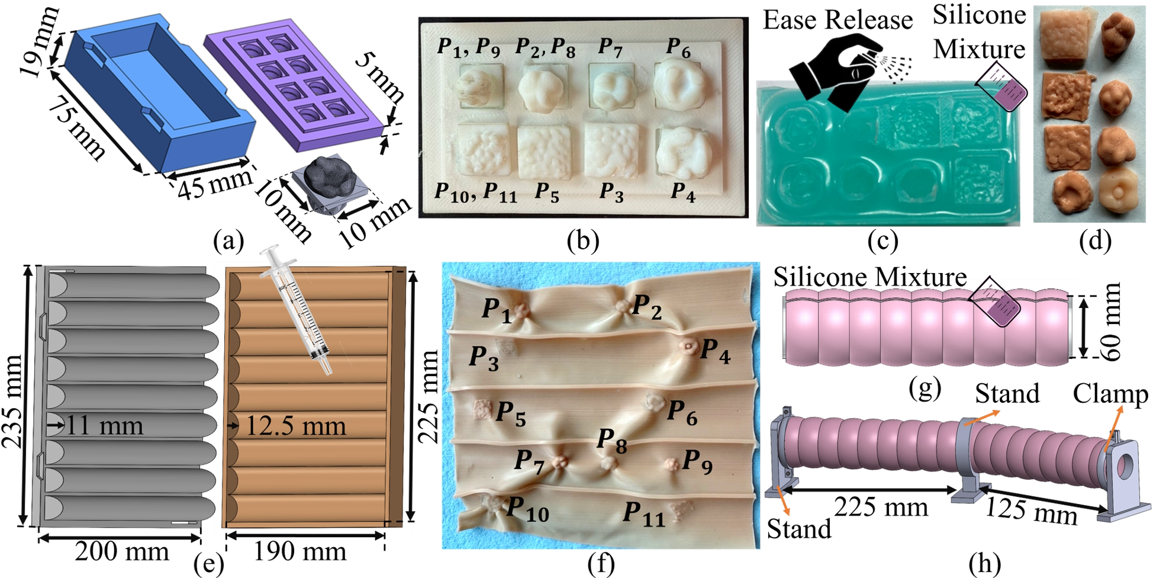
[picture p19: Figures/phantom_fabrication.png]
Colon phantom fabrication


Because commercial colonoscopy simulators are designed primarily for navigation training and do not contain detectable polyps, we developed a custom silicone colon phantom with **embedded colorectal cancer (CRC) polyps of varying stages**, enabling end-to-end evaluation of both maneuverability and AI-enabled lesion detection. Fabrication proceeds in two stages: forming the polyps, then casting the colon wall with the polyps embedded.

---

## Polyp Fabrication

Polyps were designed to span the **Paris classification** of CRC lesion morphologies.

1. **Rigid masters.** High-resolution polyp masters were printed on a Digital Anatomy Printer (Stratasys J750) in Vero PureWhite to capture fine surface texture.
2. **Negative molds.** Each master was used to cast a negative silicone mold inside a 3D-printed container and cap (Prusa i3 MK3S+, ABS).
3. **Silicone casts.** After demolding, the mold surface was treated with Ease Release 200 (Mann Technologies), then filled with a flesh-tone-pigmented silicone mixture (Smooth-On). This yields the final soft polyps — **11 polyps, labeled P1–P11.**

---

## Colon Phantom Fabrication

The phantom wall is cast using a simple, modular, **unfolded mold** (a flat base mold plus a core cap), avoiding the leakage, complex assembly, and polyp-embedding difficulties of traditional core-based molding. Dimensions follow the reported average human colon (external diameter **D ≈ 60 mm**):

- **Base mold:** nine half-cylinder channels, radius **r = 12.5 mm**, spanning a width **W = 190 mm** (the phantom circumference once wrapped).
- **Core cap:** nine half-cylinders, radius **r = 11 mm**, producing a uniform **1.5 mm wall thickness** against the base mold.

**Process:**

1. Mix Ecoflex 00-30 (Smooth-On, parts A:B = 1:1), pigment flesh-tone, and degas in a vacuum chamber.
2. Dispense ≈ 10 mL into each half-cylinder channel; randomly place the 11 prefabricated polyps on the poured layer (ensuring adhesion while preserving surface texture).
3. Assemble and clamp the core cap to hold the polyps and maintain uniform wall thickness; cure ≈ 4 hours at room temperature.
4. Demold the flat sheet, wrap it around a cylindrical tube, and secure with a holder; seal the seam with Ecoflex 00-35 Fast (Smooth-On) to form a continuous cylinder.
5. Fabricate additional segments and join them with the same procedure to extend length. Each segment is **225 mm** long.

The fully assembled phantom is supported by 3D-printed stands and clamps to form **straight or curved** sections, permanently embedding clinically representative polyps for both navigation and detection studies.

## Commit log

2026-06-23 Add experimental setup, hardware platform, and documentation updates
    - Introduced a new experimental setup image to enhance visual understanding.
    - Revised the README to provide a clearer overview of the experimental setup and hardware platform, including detailed descriptions of the control and robotic systems.
    - Created new documentation files:
    - `assembly.md` detailing CAD and assembly files for reproduction.
    - `bill-of-materials.md` listing components used in the OpenRC platform.
    - `hardware.md` summarizing the hardware platform and its subsystems.
    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
2026-06-24 Refine documentation for assembly and bill of materials.
    [2006N518_302 Stainless Steel Corrosion-Resistant Compression Springs_2006N518.STEP, 2023_01_25_20_50_19_0381.stp.STEP, Adptor-1_默认.STEP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]
2026-06-24 Add feeding module STL and STEP files. Update BoM
    [100mm-Lead Screw_97783A170.STEP, 2006N518_302 Stainless Steel Corrosion-Resistant Compression Springs_2006N518.STEP, 2023_01_25_20_50_19_0381.stp.STEP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]
